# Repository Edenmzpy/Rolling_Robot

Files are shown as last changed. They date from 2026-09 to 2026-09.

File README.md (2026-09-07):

<div align="center">
  Rolling Robot project banner

  <br />

  <a href="README.md"><strong>English</strong></a> ·
  <a href="README.zh-CN.md">简体中文</a>

  <br /><br />

  
  
  
  
  
</div>

## An untethered robot that rolls by changing its own shape

Rolling Robot is a B.Eng. capstone project by **Yufeng Zeng (曾宇烽)** at South China University of Technology. Twelve pneumatic–tendon soft legs are arranged on the faces of a regular dodecahedral body. Coordinated contraction and extension shift the robot's center of mass beyond its support polygon, producing omnidirectional rolling without an external air line.

> This repository contains the embedded firmware, Keil projects, prebuilt binaries, and mechanical source files used for the prototype.

## What makes it different

| | Design choice | Purpose |
|---|---|---|
| **01** | Dodecahedral body with 12 actuated faces | Similar rolling behavior in multiple directions |
| **02** | Pneumatic–tendon coupled soft leg | Tendons provide contraction while air pressure tunes stiffness and extension force |
| **03** | Interconnected three-leg pneumatic circuit | Reuses displaced air during a “two contract, one extends” step |
| **04** | Distributed STM32 control | Separates handheld input from real-time sensing and actuation on the robot |
| **05** | IMU-based state estimation | Identifies the supporting vertices and selects the next motion direction |

## System architecture

```mermaid
flowchart LR
    C[Handheld controller<br/>STM32F103] -->|NRF24L01<br/>2.4 GHz| R[Robot controller<br/>STM32F407 + FreeRTOS]
    I[9-axis IMU] --> R
    P[Pressure sensor] --> R
    R --> S[12 tendon servos]
    R --> A[Pump + valves]
    S --> L[Pneumatic–tendon<br/>soft legs]
    A --> L
    L --> M[Dodecahedral body<br/>omnidirectional rolling]
```

The robot-side firmware runs five application tasks connected through FreeRTOS queues:

- `wit_imu` — attitude, supporting-vertex, direction, and velocity estimation
- `nrf_recv` — command reception and set-point updates
- `charge_task` — pressure control with PID-assisted soft PWM
- `move_task` — gait selection and interpolated servo motion
- `nrf_send` — telemetry back to the handheld controller

## Prototype specifications

| Parameter | Value |
|---|---|
| Body geometry | Regular dodecahedron |
| Circumscribed radius | 150 mm |
| Soft legs | 12 |
| Nominal leg travel | 75 mm |
| Actuation | Tendon-driven contraction + pneumatic extension/stiffness control |
| Robot MCU | STM32F407VET6, Cortex-M4, 168 MHz |
| Controller MCU | STM32F103C8T6, Cortex-M3 |
| Wireless link | NRF24L01, 2.4 GHz |
| State sensing | WIT 9-axis IMU |
| Control software | STM32 HAL + FreeRTOS |

## Experimental results

- Peak-window speed on flat ground: **0.267 m/s at 15 kPa**
- Full-run average speed at the same pressure: **0.053 m/s**
- Continuous rolling with a **1 kg payload**, with a measured 43% speed reduction
- Demonstrated locomotion on flat ground, gravel, and grass
- Interconnected pneumatic actuation reduced tendon tension by approximately **34%** and increased extension output force to nearly **3×** the uncoupled case

These values describe the tested prototype and its experimental setup; they are not general performance guarantees.

## Repository map

| Path | Contents |
|---|---|
| [`Code/`](Code/) | STM32CubeMX/Keil firmware for the robot and handheld controller |
| [`Code/RollingRobot/RollingRobot/Task/`](Code/RollingRobot/RollingRobot/Task/) | Robot application tasks and control logic |
| [`Mechanical_Design/`](Mechanical_Design/) | SolidWorks assemblies, printable STL files, and 3MF files |
| [`firmware/`](firmware/) | Prebuilt HEX images for both STM32 targets |
| [`docs/assets/`](docs/assets/) | Repository artwork and documentation assets |

The generated STM32 HAL/CMSIS sources remain in the repository so the projects can be opened without recreating them in STM32CubeMX. Keil object files, build reports, and machine-specific settings are intentionally excluded.

## Build and flash

### Option A — use the prebuilt firmware

Flash the matching image from [`firmware/`](firmware/) with STM32CubeProgrammer or another ST-Link-compatible tool:

- `rolling-robot.hex` — STM32F407VET6 robot controller
- `controller.hex` — STM32F103C8T6 handheld controller

### Option B — build from source

1. Install Keil MDK-ARM with the STM32F1 and STM32F4 device packs.
2. Open the relevant project:
   - Robot: [`Code/RollingRobot/RollingRobot/MDK-ARM/RollingRobot.uvprojx`](Code/RollingRobot/RollingRobot/MDK-ARM/RollingRobot.uvprojx)
   - Controller: [`Code/RollingRobot/Controller/Controller/MDK-ARM/Controller.uvprojx`](Code/RollingRobot/Controller/Controller/MDK-ARM/Controller.uvprojx)
3. Build the target and flash it through ST-Link.

Hardware pin assignments and peripheral initialization are defined in the corresponding `.ioc` files and generated `Core/` sources.

## Mechanical files

The [`Mechanical_Design/Model/`](Mechanical_Design/Model/) directory includes editable SolidWorks parts/assemblies and printable exports. Original filenames are retained because changing them can break assembly references. See the [mechanical design notes](Mechanical_Design/README.md) before reorganizing those files locally.

## Project scope

This is an archived research prototype rather than a plug-and-play kit. Reproduction requires the original electronics, pneumatic components, servo calibration, and mechanical assembly. The repository does not currently include a complete bill of materials or wiring diagram.

## Author and acknowledgment

Developed by **Yufeng Zeng (曾宇烽)** as an undergraduate capstone project at the School of Robotics, South China University of Technology.

Advisor: **Prof. Yunquan Li (李云泉)**

The pneumatic–tendon coupling concept builds on prior work by Fu et al. on untethered soft rolling robots (IEEE Robotics and Automation Letters, 2024).

## License

No open-source license has been added yet. Unless a license is added, copyright remains with the author and reuse requires permission.

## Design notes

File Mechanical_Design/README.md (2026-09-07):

# Mechanical design files

This directory contains the source and printable geometry for the Rolling Robot prototype.

## File formats

| Format | Use |
|---|---|
| `.SLDASM` | SolidWorks assemblies; use these to inspect component relationships |
| `.SLDPRT` | Editable SolidWorks part files |
| `.STL` | Mesh exports for slicing or viewing without SolidWorks |
| `.3MF` | Print-ready project files for selected cylindrical and ring components |

All design files are currently stored in [`Model/`](Model/). The Chinese filenames are the original working names from the prototype. They have not been translated or reorganized because SolidWorks assemblies may store path-based references to those exact names.

## Recommended workflow

1. Copy the complete `Model/` directory before making changes.
2. Open an assembly from the copied directory in SolidWorks.
3. If SolidWorks reports missing references, use **Find References** and point it to the same copied directory.
4. Export a fresh STL/3MF after editing instead of overwriting the provided printable file.

Dimensions, clearances, and material choices reflect the original research prototype. Verify them against your printer, actuator, corrugated tube, and fasteners before fabrication.

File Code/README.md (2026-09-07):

# Firmware workspace

The embedded software is split into two STM32CubeMX/Keil projects.

| Target | MCU | Project file | Responsibility |
|---|---|---|---|
| Robot body | STM32F407VET6 | [`RollingRobot/RollingRobot/MDK-ARM/RollingRobot.uvprojx`](RollingRobot/RollingRobot/MDK-ARM/RollingRobot.uvprojx) | Sensing, pressure regulation, gait control, servo actuation, and telemetry |
| Handheld controller | STM32F103C8T6 | [`RollingRobot/Controller/Controller/MDK-ARM/Controller.uvprojx`](RollingRobot/Controller/Controller/MDK-ARM/Controller.uvprojx) | User input, status display, and wireless command transmission |

## Robot application layer

The project-specific FreeRTOS code lives in [`RollingRobot/RollingRobot/Task/`](RollingRobot/RollingRobot/Task/):

| Source | Role |
|---|---|
| `wit_imu.c` | Parses IMU data and estimates pose, supporting vertices, direction, and speed |
| `nrf_recv.c` | Receives remote commands and publishes motion/pressure set points |
| `pump_charge.c` | Samples pressure and drives the pump with PID-assisted soft PWM |
| `servo_move.c` | Maps the requested gait to 12 servo channels and interpolates motion |
| `nrf_send.c` | Packages pressure, motion, and IMU telemetry for the controller |

Device drivers are under each target's `Hardware/` directory. STM32 HAL, CMSIS, and FreeRTOS middleware are generated or vendor-provided dependencies and remain alongside the project for reproducibility.

## Build hygiene

The `MDK-ARM/` directories contain only portable project inputs. Keil outputs (`.o`, `.axf`, `.map`, reports, and dependency files) and user-specific `.uvguix.*` settings are ignored. Verified prebuilt HEX files from the original project snapshot are kept separately in [`../firmware/`](../firmware/).

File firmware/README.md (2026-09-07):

# Prebuilt firmware

These files were preserved from the original project snapshot before generated Keil build directories were removed from version control.

| File | Target | SHA-256 |
|---|---|---|
| `controller.hex` | STM32F103C8T6 handheld controller | `15e107987f9907d8fa387220b6d4a9f74bc74f0a82418485e1e0af88ece7027e` |
| `rolling-robot.hex` | STM32F407VET6 robot controller | `288effec6bad4e7ef87aea7a6e5c70c6d34b9f251354cafb380e96b99d466670` |

Flash the correct image with STM32CubeProgrammer or another ST-Link-compatible tool. Hardware compatibility is limited to the matching prototype boards and pin assignments in the source projects.

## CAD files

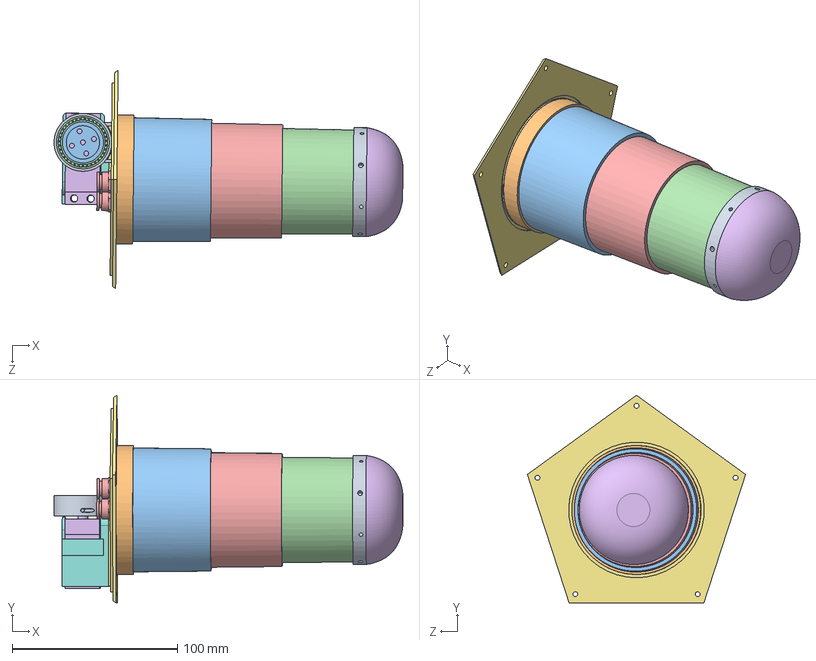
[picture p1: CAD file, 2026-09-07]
Mechanical_Design/Model/套筒单腿装配体-躺-长.SLDASM
211.2 x 125.6 x 132.0 mm
绕线盘外壳-sts
金属舵盘
绕线盘-舵机
轴承25-32-4
快插接头-PC601 x 2
足部
GX-X80-2
GX-X80舵机外壳-pc
大波纹管底部-套筒
大波纹管顶部-套筒
大筒
小筒吗
中筒
GX-X80舵机

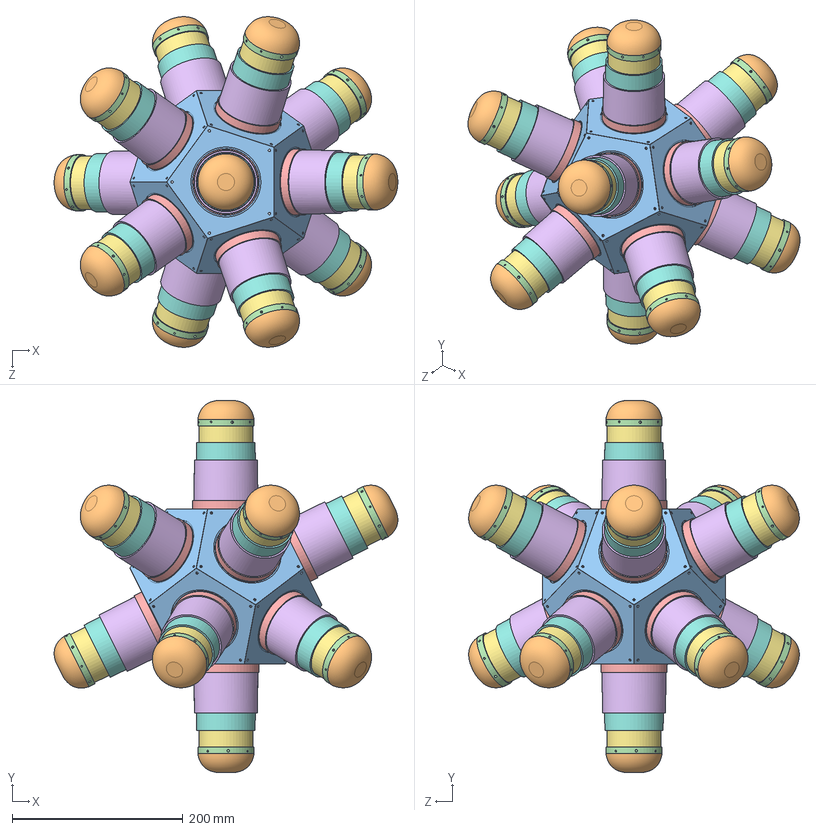
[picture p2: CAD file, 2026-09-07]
Mechanical_Design/Model/渲染模型.SLDASM
403.0 x 436.2 x 387.7 mm
十二面体-带支架
足部 x 12
GX-X80-2 x 12
大波纹管底部-套筒 x 12
大波纹管顶部-套筒 x 12
大筒 x 12
小筒吗 x 12
中筒 x 12
姿态传感器

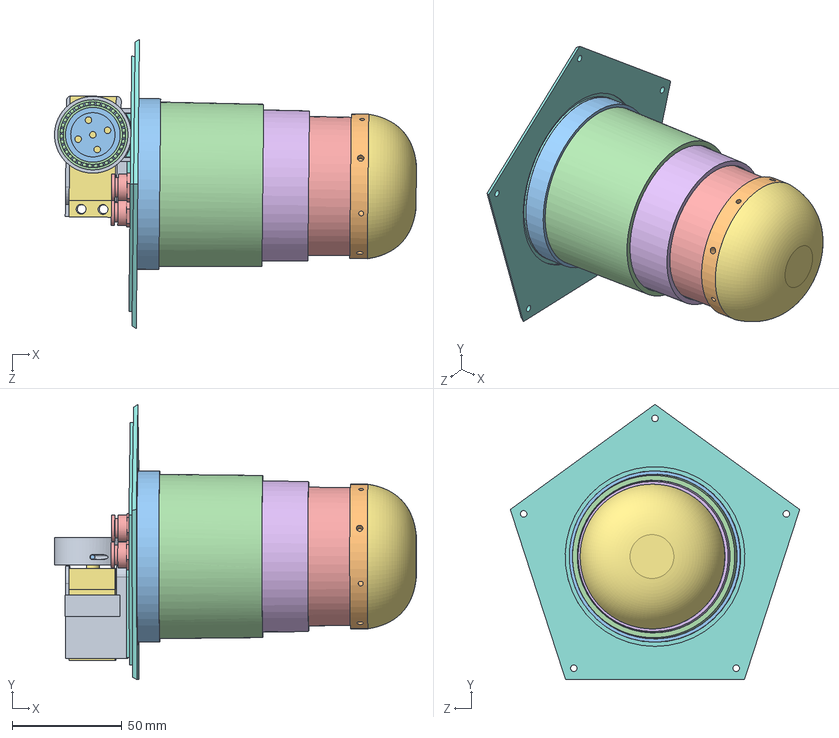
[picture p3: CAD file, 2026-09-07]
Mechanical_Design/Model/套筒单腿装配体-躺-短.SLDASM
165.2 x 125.6 x 132.0 mm
绕线盘外壳-sts
金属舵盘
绕线盘-舵机
轴承25-32-4
快插接头-PC601 x 2
正常腿
足部
GX-X80-2
GX-X80舵机外壳-pc
大波纹管底部-套筒
大波纹管顶部-套筒
大筒
小筒吗
中筒
GX-X80舵机

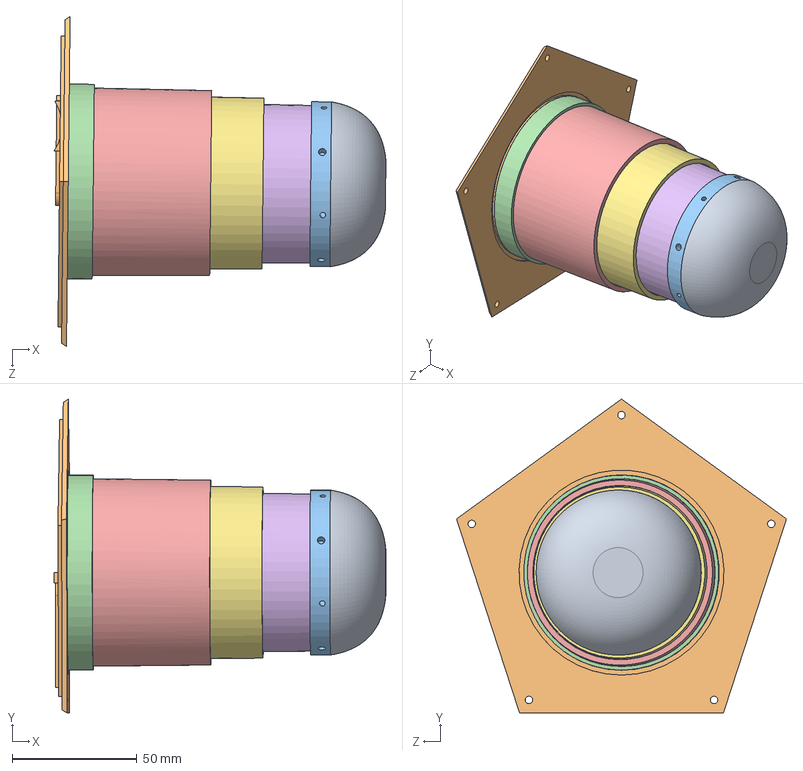
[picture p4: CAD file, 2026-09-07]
Mechanical_Design/Model/渲染模型-2.SLDASM
132.8 x 125.6 x 132.0 mm
足部
GX-X80-2
大波纹管底部-套筒
大波纹管顶部-套筒
大筒
小筒吗
中筒

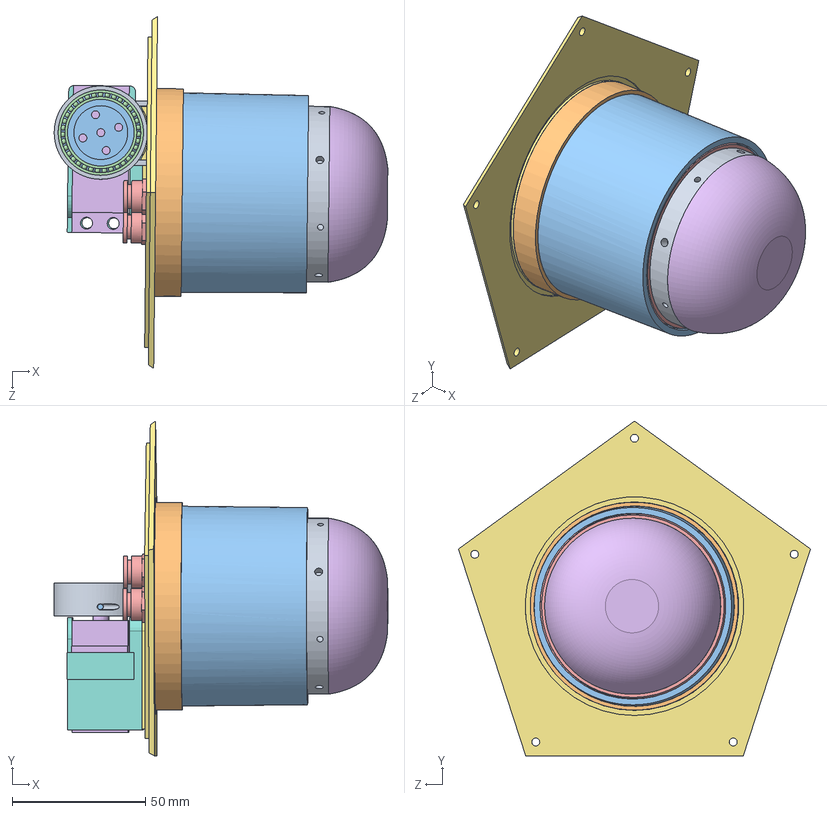
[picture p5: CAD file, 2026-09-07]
Mechanical_Design/Model/套筒单腿装配体-躺-最短.SLDASM
125.2 x 125.6 x 132.0 mm
绕线盘外壳-sts
金属舵盘
绕线盘-舵机
轴承25-32-4
快插接头-PC601 x 2
足部
GX-X80-2
GX-X80舵机外壳-pc
大波纹管底部-套筒
大波纹管顶部-套筒
大筒
小筒吗
中筒
GX-X80舵机

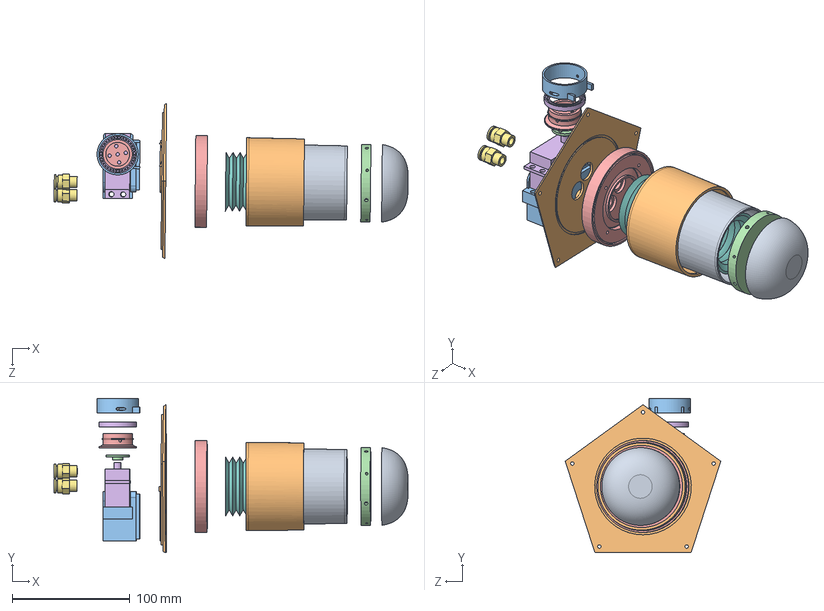
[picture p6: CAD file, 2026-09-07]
Mechanical_Design/Model/套筒单腿装配体-躺-短-爆炸图.SLDASM
300.4 x 131.0 x 132.0 mm
绕线盘外壳-sts
金属舵盘
绕线盘-舵机
轴承25-32-4
快插接头-PC601 x 2
正常腿
足部
GX-X80-2
GX-X80舵机外壳-pc
大波纹管底部-套筒
大波纹管顶部-套筒
大筒
小筒吗
GX-X80舵机

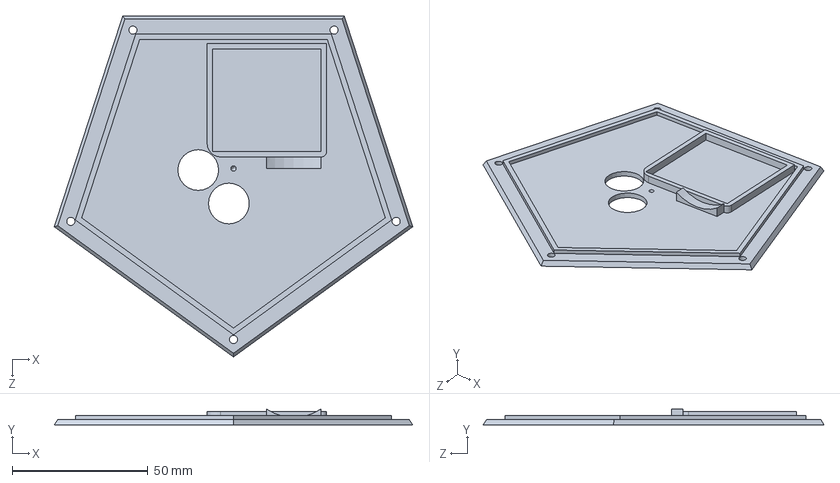
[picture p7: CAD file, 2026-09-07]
Mechanical_Design/Model/GX-X80-2.SLDPRT
132.0 x 5.83 x 125.6 mm

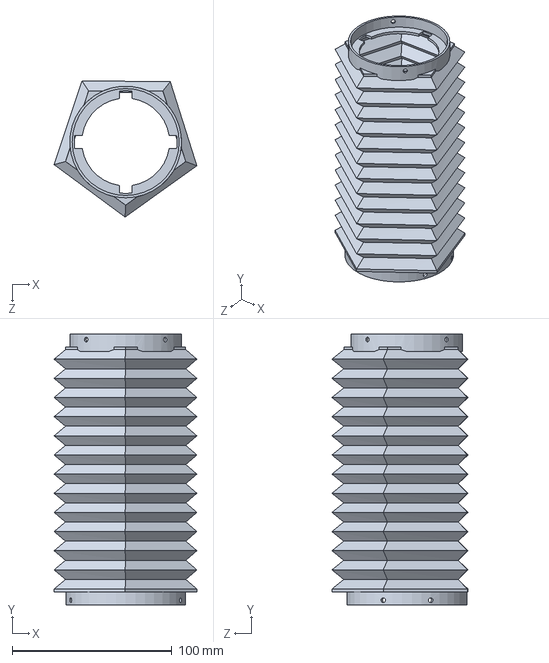
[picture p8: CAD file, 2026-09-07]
Mechanical_Design/Model/薄外壳-五边形.SLDPRT
89.5 x 169.8 x 85.3 mm

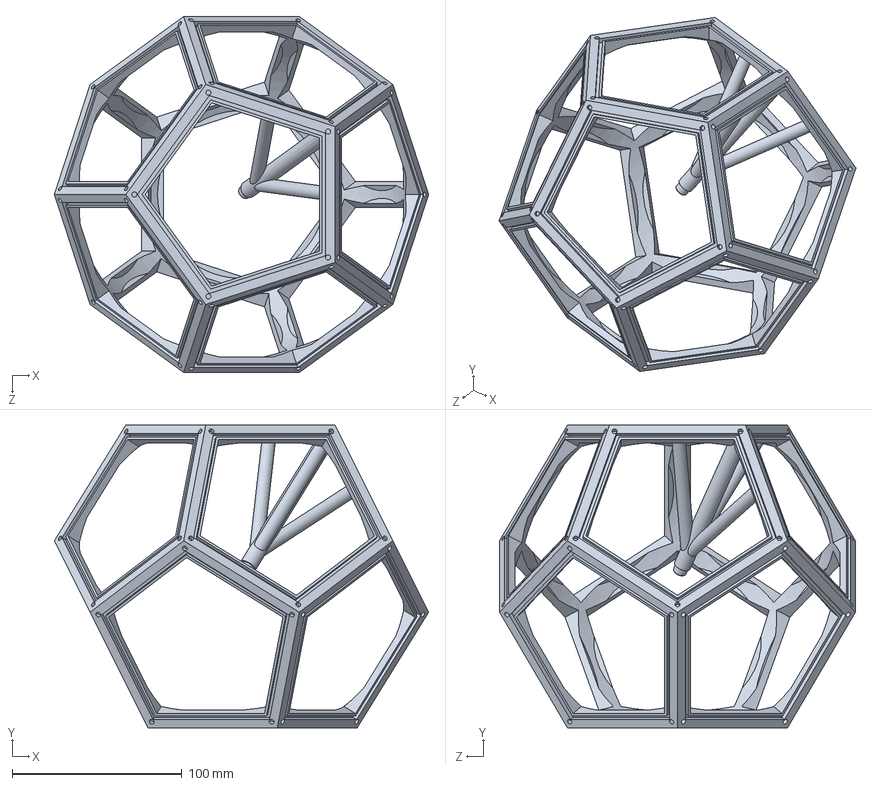
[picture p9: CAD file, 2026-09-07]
Mechanical_Design/Model/十二面体-带支架.SLDPRT
220.2 x 178.2 x 209.4 mm

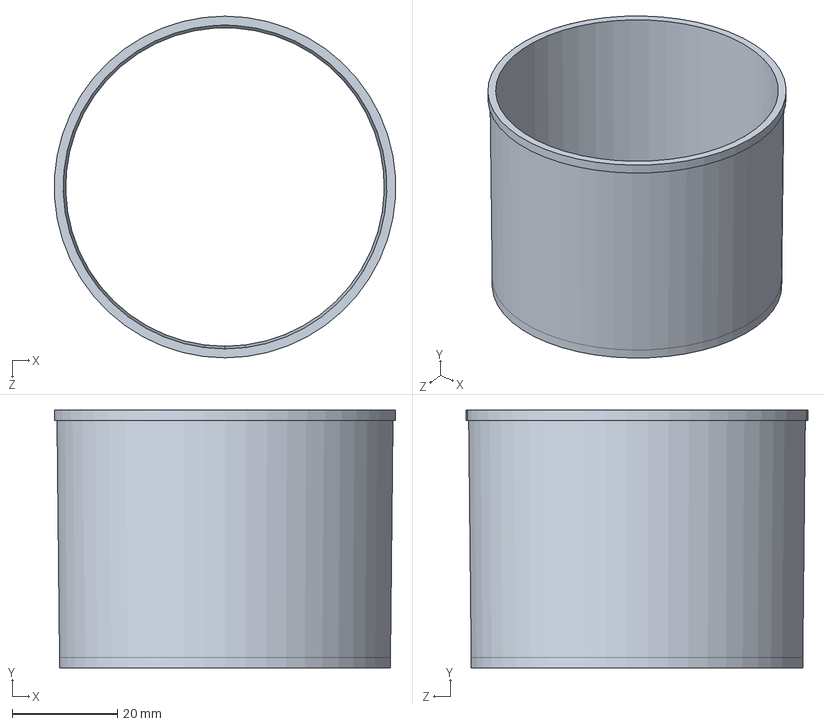
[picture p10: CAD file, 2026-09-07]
Mechanical_Design/Model/小筒吗.SLDPRT
64.8 x 49.0 x 64.9 mm

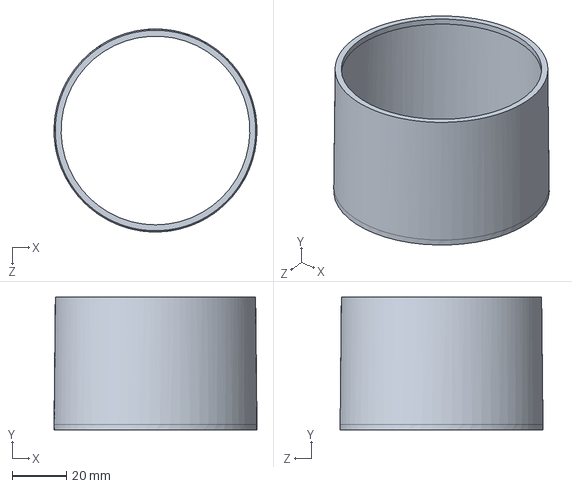
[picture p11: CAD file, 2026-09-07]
Mechanical_Design/Model/大筒.SLDPRT
75.0 x 49.0 x 75.0 mm

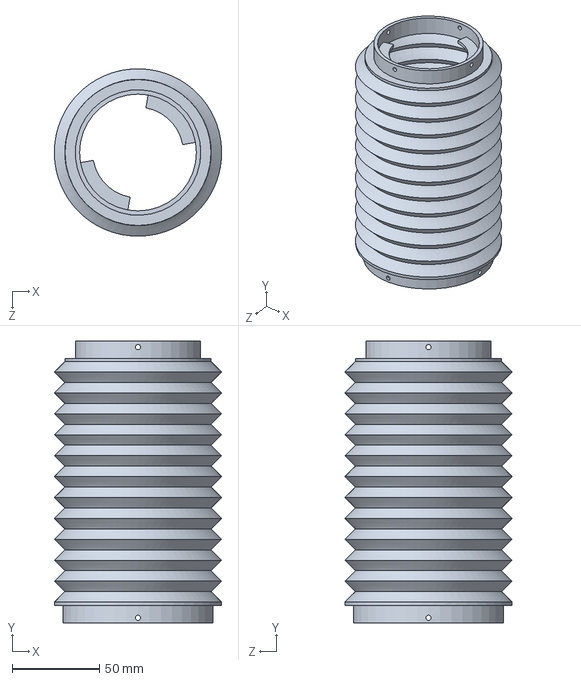
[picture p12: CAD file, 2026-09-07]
Mechanical_Design/Model/薄外壳-支架款.SLDPRT
96.0 x 161.8 x 96.0 mm

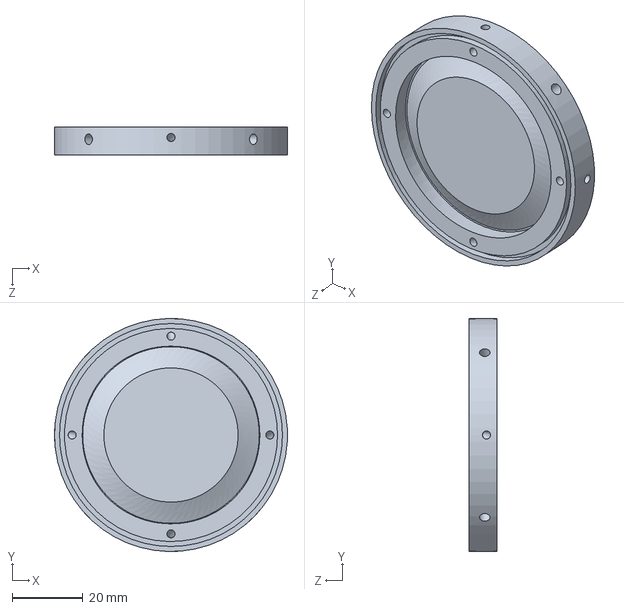
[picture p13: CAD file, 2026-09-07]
Mechanical_Design/Model/大波纹管底部-套筒.SLDPRT
66.0 x 66.0 x 8.00 mm

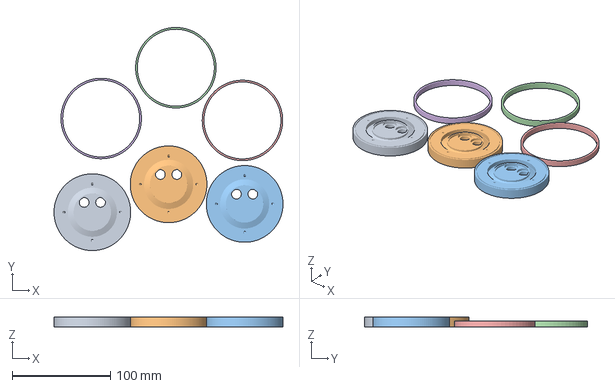
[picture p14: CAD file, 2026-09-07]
Mechanical_Design/Model/1.3mf
232.9 x 226.9 x 10.0 mm
大波纹管顶部-套筒.STL x 3
圆环 x 3

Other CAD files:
Mechanical_Design/Model/套筒十二面体装配体.SLDASM
Mechanical_Design/Model/套筒单腿装配体-躺.SLDASM
Mechanical_Design/Model/大波纹管顶部-套筒.SLDPRT
Mechanical_Design/Model/绕线盘外壳-sts(1).SLDPRT
Mechanical_Design/Model/GX-X80-2.STL
Mechanical_Design/Model/GX-X80舵机.SLDPRT
Mechanical_Design/Model/GX-X80舵机外壳-pc.SLDPRT
Mechanical_Design/Model/GX-X80舵机外壳-pc.STL
Mechanical_Design/Model/中筒.3MF
Mechanical_Design/Model/中筒.SLDPRT
Mechanical_Design/Model/十二面体-带支架.STL
Mechanical_Design/Model/圆环.3MF
Mechanical_Design/Model/圆环.SLDPRT
Mechanical_Design/Model/圆环.STL
Mechanical_Design/Model/大波纹管底部-套筒.STL
Mechanical_Design/Model/大波纹管底部-带支架.SLDPRT
Mechanical_Design/Model/大波纹管底部-带支架.STL
Mechanical_Design/Model/大波纹管顶部-套筒.STL
Mechanical_Design/Model/大波纹管顶部-带支架.SLDPRT
Mechanical_Design/Model/大波纹管顶部-带支架.STL
Mechanical_Design/Model/大筒.3MF
Mechanical_Design/Model/姿态传感器.SLDPRT
Mechanical_Design/Model/小筒吗.3mf
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

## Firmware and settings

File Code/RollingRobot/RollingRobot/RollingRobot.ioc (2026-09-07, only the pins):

Mcu.UserName=STM32F407VETx
PA1.Signal=ADCx_IN1
PA10.Signal=USART1_RX
PA13.Signal=SYS_JTMS-SWDIO
PA14.Signal=SYS_JTCK-SWCLK
PA2.Signal=USART2_TX
PA3.Signal=USART2_RX
PA6.Signal=S_TIM3_CH1
PA7.Signal=S_TIM3_CH2
PA9.Signal=USART1_TX
PB0.Signal=S_TIM3_CH3
PB1.Signal=S_TIM3_CH4
PB12.Signal=GPIO_Output
PB13.Signal=SPI2_SCK
PB14.Signal=SPI2_MISO
PB15.Signal=SPI2_MOSI
PB6.Signal=S_TIM4_CH1
PB7.Signal=S_TIM4_CH2
PB8.Signal=S_TIM4_CH3
PB9.Signal=S_TIM4_CH4
PC10.Signal=GPIO_Output
PC11.Signal=GPIO_Output
PC12.Signal=GPIO_Output
PD8.Signal=GPXTI8
PD9.Signal=GPIO_Output
PE11.Signal=S_TIM1_CH2
PE13.Signal=S_TIM1_CH3
PE14.Signal=S_TIM1_CH4
PE9.Signal=S_TIM1_CH1
PH0-OSC_IN.Signal=RCC_OSC_IN
PH1-OSC_OUT.Signal=RCC_OSC_OUT

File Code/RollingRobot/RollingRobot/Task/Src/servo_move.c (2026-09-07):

#include "FreeRTOS.h"
#include "task.h"
#include "cmsis_os.h"
#include "queue.h"

#include "tim.h"
#include <math.h>
#include <stdio.h>

#include "servo_move.h"
#include "wit_imu.h"
#include "nrf_recv.h"

// 引用外部消息队列
extern QueueHandle_t qMove; // from nrf_recv.c
extern QueueHandle_t qFeet; // from wit_imu.c

const uint16_t mid_pos[12] =
{
    1500,1500,1500,1500,
    1500,1500,1500,1500,
    1500,1500,1500,1500
}; // 对应舵机中位
const uint16_t long_pos[12] =
{ 
    2500,2500,2500,2500,
    2500,2500,2500,2500,
    2500,2500,2500,2500
};// 对应舵机伸长位
const uint16_t short_pos[12] =
{ 
    500,500,500,500,
    500,500,500,500,
    500,500,500,500
};// 对应舵机缩短位

// 12个足端当前位置缓存
static uint16_t servo_curr[12];

typedef struct
{
    TIM_HandleTypeDef *htim;
    uint32_t channel;
} ServoMap_t; // 舵机映射信息

// 舵机编号与定时器通道映射
static const ServoMap_t servo_map[12] =
{
    { &htim1, TIM_CHANNEL_1 }, // foot 0
    { &htim1, TIM_CHANNEL_2 }, // foot 1
    { &htim1, TIM_CHANNEL_3 }, // foot 2
    { &htim1, TIM_CHANNEL_4 }, // foot 3

    { &htim3, TIM_CHANNEL_1 }, // foot 4
    { &htim3, TIM_CHANNEL_2 }, // foot 5
    { &htim3, TIM_CHANNEL_3 }, // foot 6
    { &htim3, TIM_CHANNEL_4 }, // foot 7

    { &htim4, TIM_CHANNEL_1 }, // foot 8
    { &htim4, TIM_CHANNEL_2 }, // foot 9
    { &htim4, TIM_CHANNEL_3 }, // foot 10
    { &htim4, TIM_CHANNEL_4 }, // foot 11
};

// 返回需要伸长的足端下标
int choose_feet(MovePkt* move, FeetPkt* ground_feet)
{
    float dx = cosf(move->MoveDir);
    float dy = sinf(move->MoveDir);

    int best_idx = -1;
    float best_proj = 1e9f;

    for (int i = 0; i < 3; ++i)
    {
        float fa = ground_feet->feet[i].angle;
        float fx = cosf(fa);
        float fy = sinf(fa);

        float proj = fx * dx + fy * dy;
        if (proj < best_proj)
        {
            best_proj = proj;
            best_idx = i;
        }
    }
    return best_idx;
}

// PWM 初始化
static inline void servo_pwm_start(uint8_t foot_id)
{
    TIM_HandleTypeDef *htim = servo_map[foot_id].htim;
    uint32_t ch = servo_map[foot_id].channel;
    HAL_TIM_PWM_Start(htim, ch);
}

// 设置舵机占空比
static inline void servo_set_pulse(uint8_t foot_id, uint16_t pulse)
{
    TIM_HandleTypeDef *htim = servo_map[foot_id].htim;
    uint32_t ch = servo_map[foot_id].channel;
    __HAL_TIM_SET_COMPARE(htim, ch, pulse);
    servo_curr[foot_id] = pulse;
}

// 舵机初始化，设置中位
void servo_init_all(void)
{
    for (uint8_t id = 0; id < 12; ++id)
    {
        servo_pwm_start(id);
    }

    for (uint8_t id = 0; id < 12; ++id)
    {
        servo_set_pulse(id, mid_pos[id]);
    }
}

// 舵机分段平滑移动
void servo_move_slow(uint8_t ids[3], uint16_t targets[3], uint16_t step, TickType_t delay_tick)
{
    uint8_t finished;
    if (step == 0) step = 1;

    while (1)
    {
        finished = 1;
        for (int i = 0; i < 3; ++i)
        {
            uint8_t id = ids[i];
            if (id >= 12) continue;

            uint16_t cur = servo_curr[id];
            uint16_t tgt = targets[i];

            if (cur < tgt)
            {
                uint16_t next = cur + step;
                if (next > tgt) next = tgt;
                servo_set_pulse(id, next);
                if (next != tgt) finished = 0;
            }
            else if (cur > tgt)
            {
                uint16_t next = (cur > step) ? cur - step : 0;
                if (next < tgt) next = tgt;
                servo_set_pulse(id, next);
                if (next != tgt) finished = 0;
            }
        }

        if (finished) break;
        vTaskDelay(delay_tick);
    }
}

// 根据 back_index 控制伸长/缩短
void feet_move(FeetPkt* ground_feet, int back_index)
{
    uint8_t foot_ids[3];
    uint16_t targets[3];
    int j = 0;

    for (int i = 0; i < 3; ++i)
    {
        uint8_t id = ground_feet->feet[i].foot_id;

        if (i == back_index)
        {
            foot_ids[0] = id;
            targets[0] = long_pos[id];
        }
        else
        {
            foot_ids[j + 1] = id;
            targets[j + 1] = short_pos[id];
            ++j;
        }
    }

    // 平滑移动到目标
    servo_move_slow(foot_ids, targets, 75, 20);//舵机一次响应速度0.28s
    vTaskDelay(pdMS_TO_TICKS(1220));

    // 回中位
    uint16_t mid_targets[3];
    for (int i = 0; i < 3; ++i)
    {
        uint8_t id = foot_ids[i];
        mid_targets[i] = (id < 12) ? mid_pos[id] : 0;
    }
    servo_move_slow(foot_ids, mid_targets, 75, 20);
	vTaskDelay(pdMS_TO_TICKS(1220));
}//每一次运动3s


// 运动任务
void move_task(void *params)
{
    vTaskDelay(pdMS_TO_TICKS(500));

    servo_init_all();

    MovePkt move;
    FeetPkt ground_feet;
    while (1)
    {
        BaseType_t res = xQueueReceive(qMove, &move, portMAX_DELAY);
        if (res == pdTRUE)
        {
            if (move.valid == 1)
            {
                xQueuePeek(qFeet, &ground_feet, portMAX_DELAY);

                int back_index = choose_feet(&move, &ground_feet);

                feet_move(&ground_feet, back_index);
            }
        }
    }
}

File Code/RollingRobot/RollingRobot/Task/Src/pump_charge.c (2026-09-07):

#include "FreeRTOS.h"
#include "task.h"
#include "queue.h"
#include "main.h"
#include "cmsis_os.h"

#include "pump_charge.h"
#include "adc.h"
#include "tim.h"

static uint16_t adc_buf[1];//用于存储从ADC读取的传感器数据
TaskHandle_t s_pumpTaskHandle = NULL; //创建空句柄
QueueHandle_t qPressure = NULL;
QueueHandle_t qPumpCmd = NULL;

extern QueueHandle_t qMax_pre;//引用外部消息队列，from nrf_recv.c

/* 软件PWM参数 */
#define CTRL_PERIOD_MS      20      // 控制周期 20ms
#define SOFT_PWM_PERIOD_MS  200     // 软件PWM窗口 200ms
#define PRESSURE_NEAR_TH    1.0f    // 距离目标1.0以内开始PID/细调
#define DUTY_MAX            100.0f
#define DUTY_MIN            0.0f

static void pump_on(void)
{
    HAL_GPIO_WritePin(GPIOC, GPIO_PIN_12, GPIO_PIN_SET);
}

static void pump_off(void)
{
    HAL_GPIO_WritePin(GPIOC, GPIO_PIN_12, GPIO_PIN_RESET);
}

static float clampf(float x, float lo, float hi)
{
    if (x < lo) return lo;
    if (x > hi) return hi;
    return x;
}

void charge_task(void *params)
{
	s_pumpTaskHandle = xTaskGetCurrentTaskHandle();//为当前任务赋值句柄
	qPressure = xQueueCreate(1, sizeof(float)); // 创建气压队列
	qPumpCmd  = xQueueCreate(1, sizeof(PumpCmd_t));
	
	// 开启ADC和定时器，周期性触发adc，并且将adc得到的值通过dma外设赋值在adc_buf中（相当与一个后台运行）
	HAL_TIM_Base_Start(&htim8);
	HAL_ADC_Start_DMA(&hadc1, (uint32_t*)adc_buf, 1);
	
	float pressure = 0.0f;
    uint8_t max_pre = 10;
	
	/* PID参数 */
    float kp = 60.0f;
    float ki = 8.0f;
    float kd = 5.0f;

    float err = 0.0f, last_err = 0.0f;
    float integral = 0.0f;
    float derivative = 0.0f;
    float duty = 0.0f;

    uint8_t charging = 0;
	TickType_t lastWakeTime = xTaskGetTickCount();

    PumpCmd_t cmd = PUMP_CMD_NONE;
	
	while (1)
	{
		/* 非阻塞读取命令 */
        if (xQueueReceive(qPumpCmd, &cmd, 0) == pdPASS)
        {
            if (cmd == PUMP_CMD_START)
            {
                charging = 1;
                integral = 0.0f;
                last_err = 0.0f;
            }
            else if (cmd == PUMP_CMD_STOP)
            {
                charging = 0;
                pump_off();
                integral = 0.0f;
                last_err = 0.0f;
            }
        }

        /* 读取当前压力和目标压力 */
        xQueuePeek(qPressure, &pressure, 0);
        xQueuePeek(qMax_pre, &max_pre, 0);

        if (charging)
        {
            float target = (float)max_pre;
            err = target - pressure;

            if (err <= 0.0f)
            {
                /* 达到或超过目标，停止 */
                pump_off();
                integral = 0.0f;
                last_err = 0.0f;
            }
            else if (err > PRESSURE_NEAR_TH)
            {
                /* 误差较大，全速充气 */
                pump_on();
                integral = 0.0f;   // 防积分过大
                last_err = err;
            }
			else if ((err <= PRESSURE_NEAR_TH) && (err > 0.0f))

            {
                /* 目标附近：PID -> duty */
                float dt = CTRL_PERIOD_MS / 1000.0f;

                integral += err * dt;
                integral = clampf(integral, -5.0f, 5.0f);   // 抗积分饱和

                derivative = (err - last_err) / dt;
                last_err = err;

                duty = kp * err + ki * integral + kd * derivative;
                duty = clampf(duty, DUTY_MIN, DUTY_MAX);

                /* 软件PWM */
                uint32_t on_time  = (uint32_t)(SOFT_PWM_PERIOD_MS * duty / 100.0f);
                uint32_t off_time = SOFT_PWM_PERIOD_MS - on_time;

                if (on_time > 0)
                {
                    pump_on();
                    vTaskDelay(pdMS_TO_TICKS(on_time));
                }

                if (off_time > 0)
                {
                    pump_off();
                    vTaskDelay(pdMS_TO_TICKS(off_time));
                }

                /* 已经delay过了，本轮直接continue，避免再走下面固定周期delay */
                continue;
            }
        }

        vTaskDelayUntil(&lastWakeTime, pdMS_TO_TICKS(CTRL_PERIOD_MS));
    
	}
}

// ADC中断回调函数读取气压传感器
void HAL_ADC_ConvCpltCallback(ADC_HandleTypeDef *hadc)
{
	if (hadc->Instance == ADC1)
	{
		static uint32_t acc = 0;
		static uint8_t cnt = 0;

		acc += adc_buf[0];
		if (++cnt >= 10) // 取10次平均值
		{
			uint16_t avg = (uint16_t)(acc / 10u);
			float volt = ((float)avg / 4095) * 3.3;
			float pre = (volt - 0.2) * (100 / (2.7 - 0.2)); // 电压转气压
			
			acc = 0;
			cnt = 0;

			BaseType_t hpw = pdFALSE;
			xQueueOverwriteFromISR(qPressure, &pre, &hpw); // 写入气压队列
			portYIELD_FROM_ISR(hpw);
		}	
	}
}
